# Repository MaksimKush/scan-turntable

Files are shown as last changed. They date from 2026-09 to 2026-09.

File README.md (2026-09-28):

# scan-turntable

Поворотный стол для фотограмметрии / 3D-сканирования. Без дисплея: управление по USB-Serial и через Wi‑Fi точку доступа.

## Оборудование

- Мотор: Minebea Mitsumi **PM42L-048-EPAO** ×**2** (маркировка **EM-182 TB9608E**; 48 шагов/об, 7.5°; Ø42×22.2 мм, вал Ø3 мм; bipolar) — азимут + наклон
- Шкив / шестерня на валу: **spur pinion m=2 z=12** (азимут → венец платформы); опционально GT2 12T для старых сборок
- Платформа сканирования: **Ø200 мм** с **зубчатым венцом** по ободу (печать на Ender 3 плашмя)
- Драйвер: **EasyDriver** (по умолчанию 1/8 шага → 384 микрошага/об; ток ~600 мА)
- Контроллер: **ESP32-C3**

## Прошивка

PlatformIO-проект (`platformio.ini`, `src/main.cpp`). Сборка и прошивка:

```bash
pio run -t upload
```

## Проводка ESP32-C3 → EasyDriver

Общая земля обязательна.

| ESP32-C3 | EasyDriver |
|---|---|
| GPIO4 | STEP |
| GPIO5 | DIR |
| GPIO6 | ENABLE (HIGH = катушки выкл.) |
| GPIO7 | кнопка на GND (старт съёмки, необязательно) |

MS1/MS2 не подключать — на плате уже 1/8. Питание мотора: 12 В на M+/GND EasyDriver (8–30 В). ESP32 питается от USB. Не подавать 5 V EasyDriver на пины 3.3 V ESP. Ток: потенциометр по TP1 ≈ 3.6 V (~600 мА).

## Управление

**Wi‑Fi AP:** `ScanTable` / `scan1234` → http://192.168.4.1 (веб-интерфейс).

**Serial (115200):**

- `SCAN <кадров> <пауза_мс>` — съёмка по кругу
- `JOG <градусы>` — поворот
- `SPEED <микрошагов/с>` — скорость
- `STOP` — стоп

## CAD

SolidWorks в `cad/` (контур мотора — `file_07_40.gif`; азимут — шестерня × венец, см. `GEAR_rim_pinion_notes.txt`).

### Мотор (user-owned) и привод
- `Motor_PM42L_048_EPAO.SLDPRT` — **перерисован пользователем**; скрипты **не** пересобирают этот файл
- `Pinion_Spur_Z12_M2.SLDPRT` — шестерня m=2, z=12, bore Ø3, L=8; торец вала +2 мм
- `Motor_PM42L_048_EPAO_Pinion.SLDASM` — мотор + шестерня
- `Pulley_GT2_12T.SLDPRT` / `Motor_PM42L_048_EPAO_Pulley.SLDASM` — прежний вариант с ремнём GT2 (архив)

### Двухосевой стол (как Revopoint A230), 2× PM42 — печать под Ender 3
Сборка: `Turntable_Revopoint2Motor.SLDASM`  
Motor1 = азимут (шестерня → зубчатый венец Ø200), Motor2 = наклон U-люльки.  
Корпус закрытый (Base_Housing + крышки). Заметки: `PRINT_Ender3_notes.txt`, `GEAR_rim_pinion_notes.txt`.

| Файл | Габарит | Стол 220×220 |
|---|---|---|
| **`Platform_RimGear_200.SLDPRT`** | **tip Ø200 × 14 мм, z=98, m=2** | OK |
| `Base_Housing.SLDPRT` | Ø200 × 36 | OK |
| `Cover_Base_Top.SLDPRT` | Ø200 × 4 | OK |
| `Yoke_Cradle_Base.SLDPRT` | ~192×55×8 | OK |
| `Yoke_Cradle_Arm_L/R.SLDPRT` | 28×48×12 | OK |
| `Cover_Arm_Motor.SLDPRT` | 55×58×22 | OK |
| `Pinion_Spur_Z12_M2.SLDPRT` | Ø28 × ~12 | OK |
| `Shaft_Tilt.SLDPRT` | Ø8 × 190 | лучше металлический пруток |

FDM: PLA/PETG. Цель по габариту как Revopoint: **Ø200 × ~H82**.

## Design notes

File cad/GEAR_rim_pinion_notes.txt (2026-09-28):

Azimuth drive — spur pinion x rim gear (шестерня + зубчатый венец / «рейка» по ободу)
==============================================================================
Module m = 2.0 mm
Pinion:  Pinion_Spur_Z12_M2.SLDPRT     z=12   d=24   da=28   df=19    face=8  bore=Ø3
Rim:     Platform_RimGear_200.SLDPRT   z=98   d=196  da=200  df=191   face=8 + deck 6
Center distance CD = (d_rim + d_pinion)/2 = 110 mm
Shaft tip past pinion = +2 mm
Ratio = 98/12 ≈ 8.17 : 1

Placement:
  Motor1 (user Motor_PM42L_048_EPAO) in Base_Housing at X=CD=110 mm, Z=floor
  Pinion on shaft: Z = tipZ - 2 - 8  (tip sticks +2 mm past pinion)
  Platform centered on Z axis; rim teeth mesh pinion at CD

USER MOTOR: Motor_PM42L_048_EPAO.SLDPRT is user-owned — do NOT auto-rebuild.
Assembly: Motor_PM42L_048_EPAO_Pinion.SLDASM
Turntable: Turntable_Revopoint2Motor.SLDASM

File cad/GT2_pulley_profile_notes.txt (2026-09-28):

GT2 belt → pulley profile notes
================================
Source belt drawing: cad/GT2-Belt_profile_1.jpg (+ user screenshot)
Motor outline: cad/file_07_40.gif (Minebea PM42 file_07_40)

Belt (drawing)
--------------
P            = 2.00 mm
Tooth height = 0.75 mm
Total height = 1.38 mm
PLD          = 0.254 mm
Tip radius   = R0.555  (center on tooth CL)
Flank radius = R1.00   (labeled center offset 0.40 from CL)
Root fillet  = R0.15

Pulley (12T, this rebuild)
-------------------------
z            = 12
PD           = z*P/π = 12*2/π = 7.6394 mm
OD           = PD − 2×PLD = 7.6394 − 0.508 = 7.1314 mm
Length L     = 6.00 mm (no flanges)
Bore         = Ø3.00 mm
Clearance    = 0.05 mm (groove larger than belt tooth; radial)

How belt → pulley was inverted
------------------------------
1. Belt land (valley between teeth) rides at pulley OD.
2. Belt tooth tip seats in the pulley groove → groove depth ≈ tooth height
   + clearance (0.75 + 0.05 = 0.80 mm from OD toward axis).
3. Groove outline = belt tooth outline with radii enlarged by clearance:
     tip  R = 0.555 + 0.05 = 0.605 mm, center on CL at y = H_clr − R_tip
     root R = 0.15  + 0.05 = 0.20  mm, centers at x = ±(0.75 + 0.02) mm
4. Tip and root circles (with clearance) intersect; join at the upper
   intersection → closed cut polygon, circular-patterned ×12.
5. Front Plane sketch; extrude/cut along +Z.

Why R1.00 @ 0.40 was not used as a separate flank arc
------------------------------------------------------
A G1 (tangent) blend of tip R0.555 and flank R1.00 requires center-distance
|Rf − Rt| = 0.445 mm. That forces 2×Rt = 1.11 > Rf = 1.00, so the near-side
tooth join is geometrically impossible (contact falls on the far side of the
tip circle). Empirically, published GT2 polygon profiles (and this drawing’s
tip/root) are well-fit by tip R0.555 + root R0.15 alone; the labeled R1@0.40
is retained as drawing intent but omitted from the CAD flank as a separate
arc. Lateral X-scale of a forced R1@0.40 construction was rejected as it
distorts the tip radius.

Groove radii centers (belt-local mm, y=0 at land, +y into groove)
-----------------------------------------------------------------
Tip center:   ( 0.000, 0.195)  R=0.605 (with clr; 0.195 = 0.80 − 0.605)
Root centers: (±0.770, 0.200)  R=0.200
Join (approx):(±0.596, 0.299)

Assembly
--------
Motor_PM42L_048_EPAO + Pulley_GT2_12T
Shaft tip (EPAO I1≈17 from boss) = 0.8 + 1.5 + 17 = 19.3 mm from Front
Pulley Z = 11.3 .. 17.3 mm  → tip past pulley end = +2.0 mm

Motor vs file_07_40.gif
-----------------------
GIF / catalog          Model (BuildPM42Epao)
Ø42                    Ø42
22.2 MAX               0.8 + 21.4 = 22.2
flange 0.8             0.8
boss Ø10 × 1.5         Ø10 × 1.5
P=49.5±0.1             49.5
2-Ø3.5                 Ø3.5
2-R3.75                R3.75
shaft Ø3               Ø3
I1 (EPAO ≈17)          17 mm from boss
rear 1 MAX             1.0
wire 12.7 / 5.5 MAX    12.7 / 5.5, θ=45°

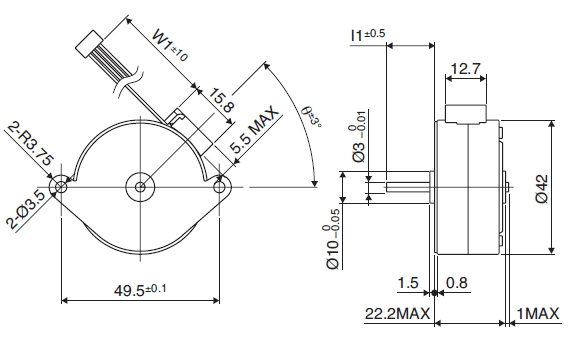
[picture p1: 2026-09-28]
cad/file_07_40.gif

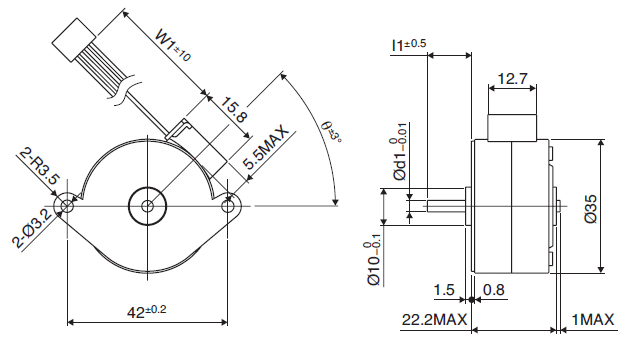
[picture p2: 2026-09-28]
cad/file_07_132.gif

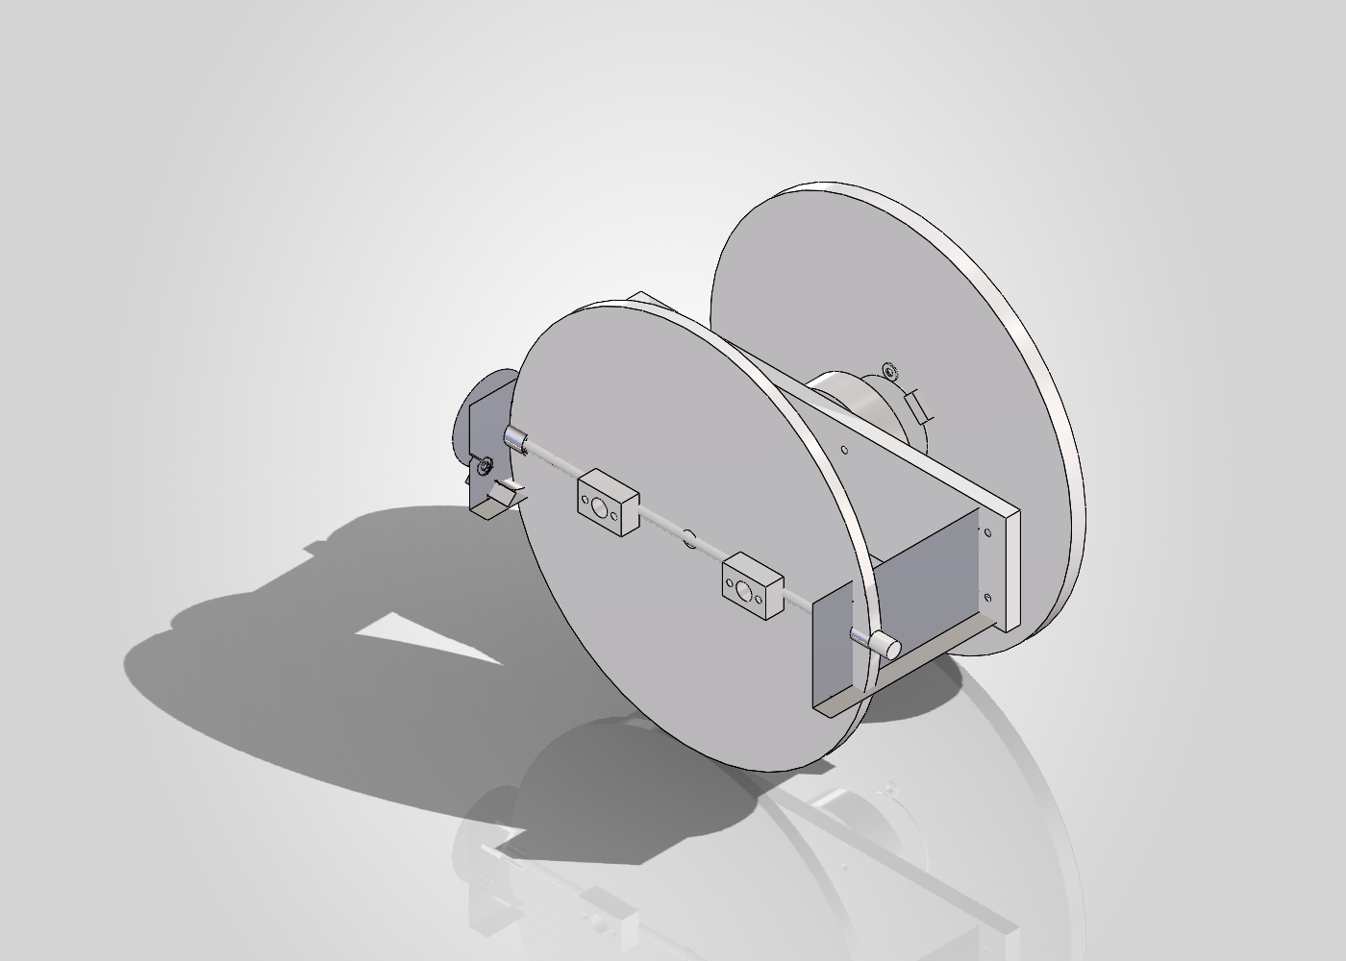
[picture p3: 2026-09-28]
cad/_preview_revopoint.png

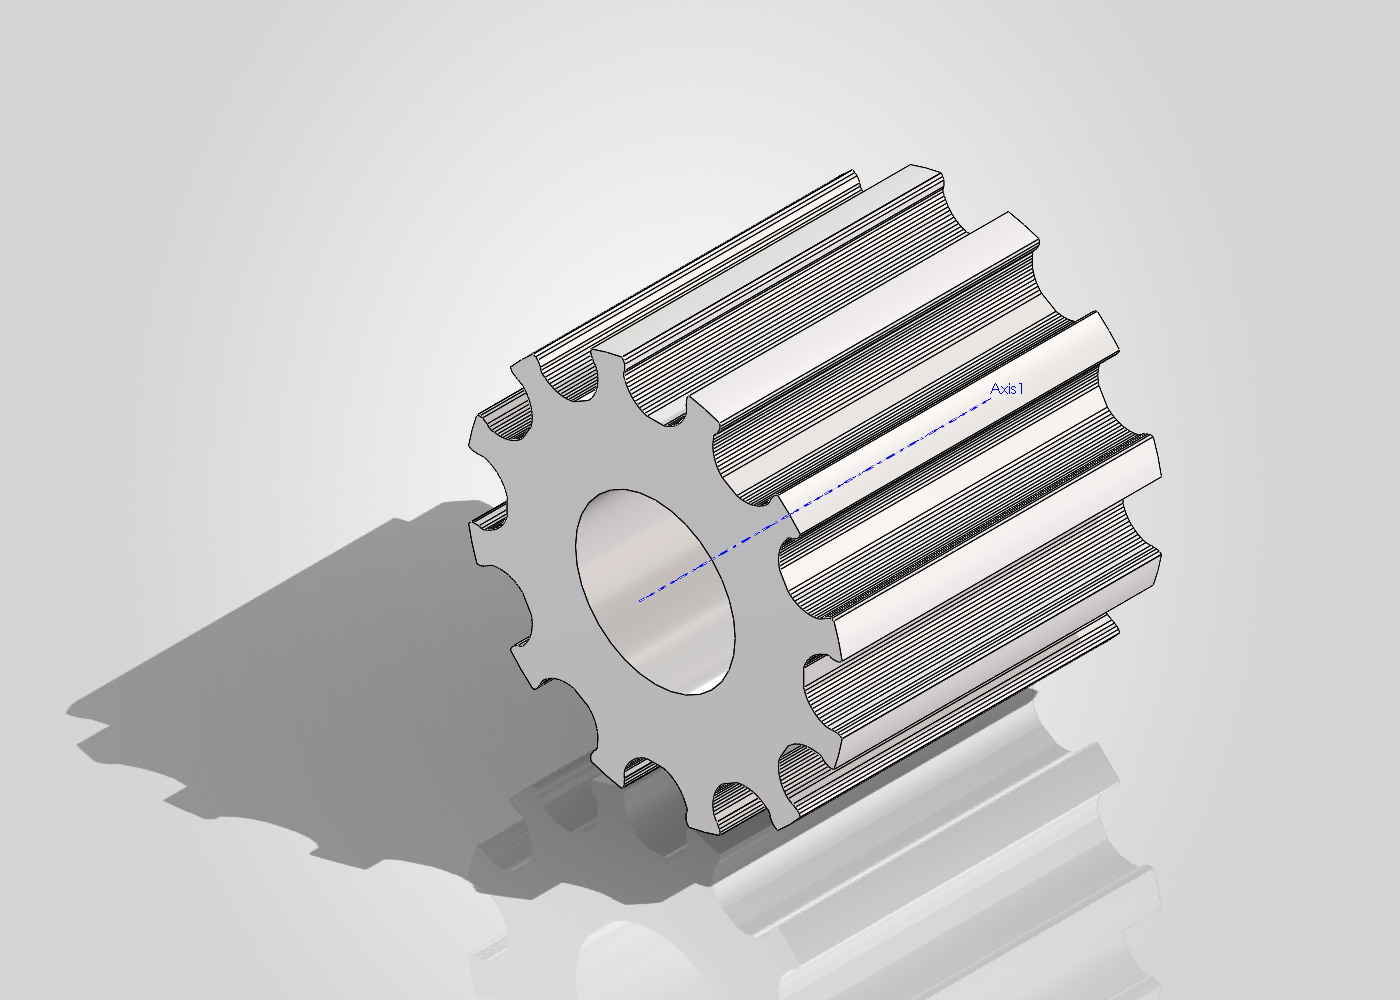
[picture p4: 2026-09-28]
cad/_preview_pulley.png

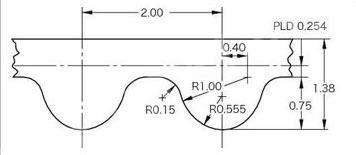
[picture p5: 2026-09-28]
cad/GT2-Belt_profile_1.jpg

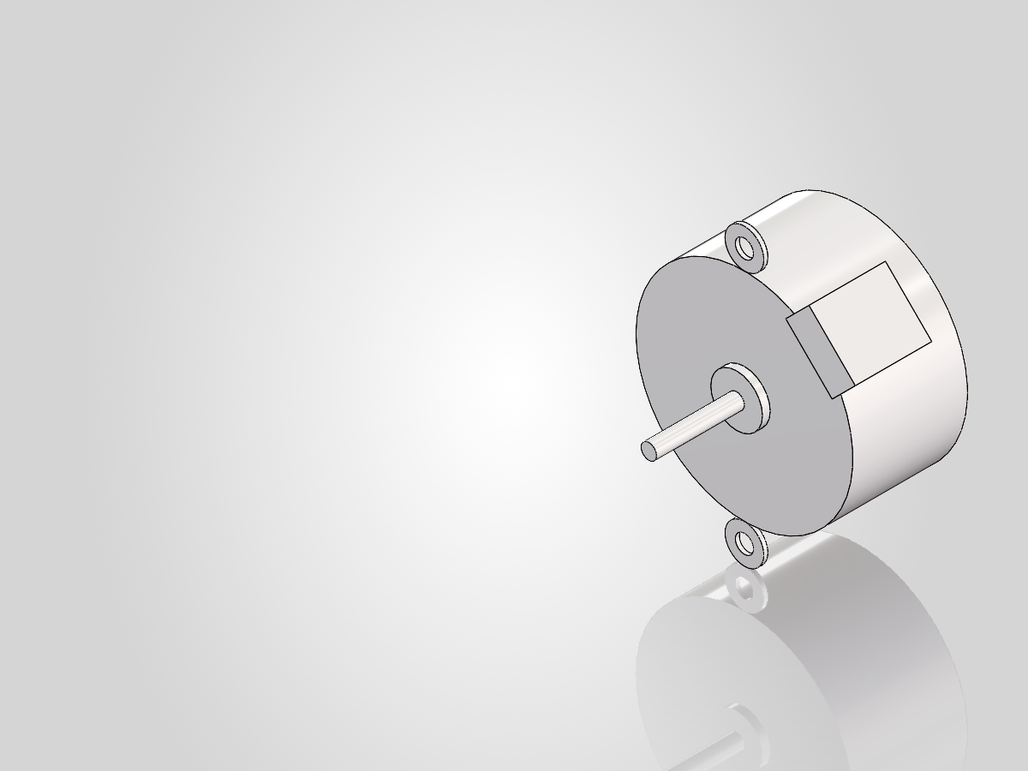
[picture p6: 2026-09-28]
cad/_preview_motor.png

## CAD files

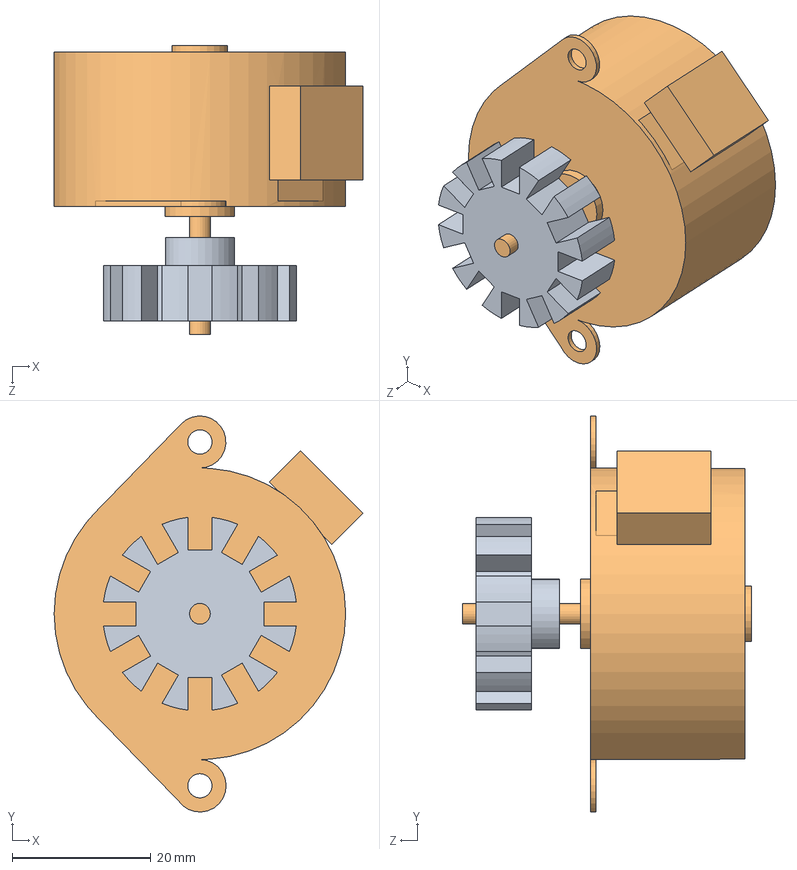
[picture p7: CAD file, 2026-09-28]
cad/Motor_PM42L_048_EPAO_Pinion.SLDASM
44.5 x 57.1 x 41.7 mm
Motor_PM42L_048_EPAO
Pinion_Spur_Z12_M2

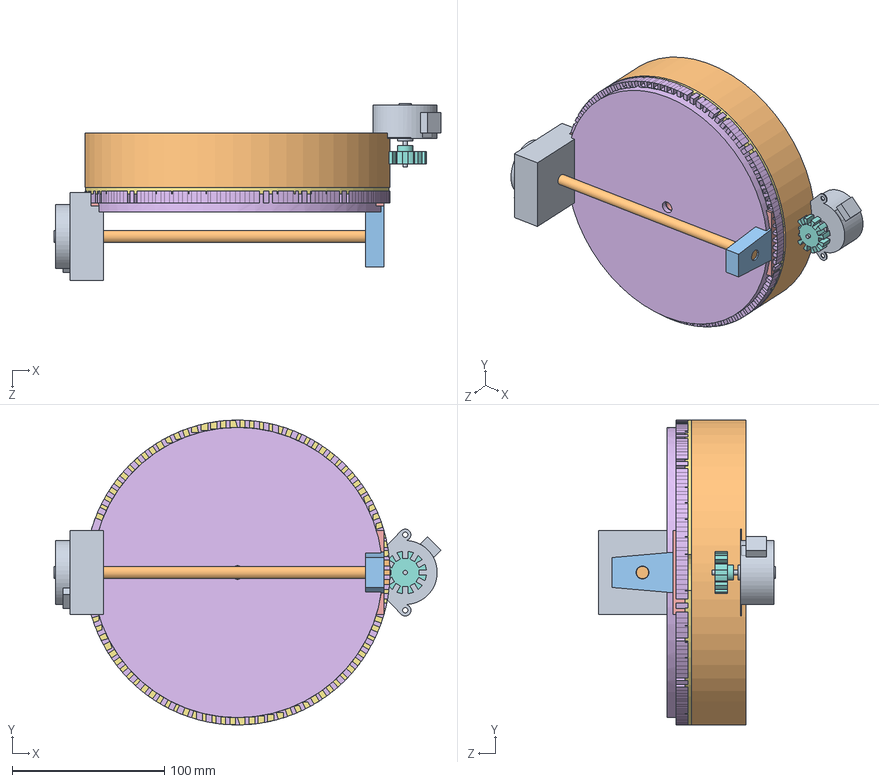
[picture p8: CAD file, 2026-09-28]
cad/Turntable_Revopoint2Motor.SLDASM
253.9 x 200.0 x 116.4 mm
Base_Housing
Motor_PM42L_048_EPAO x 2
Pinion_Spur_Z12_M2
Cover_Base_Top
Platform_RimGear_200
Yoke_Cradle_Base
Yoke_Cradle_Arm_L
Yoke_Cradle_Arm_R
Shaft_Tilt
Cover_Arm_Motor

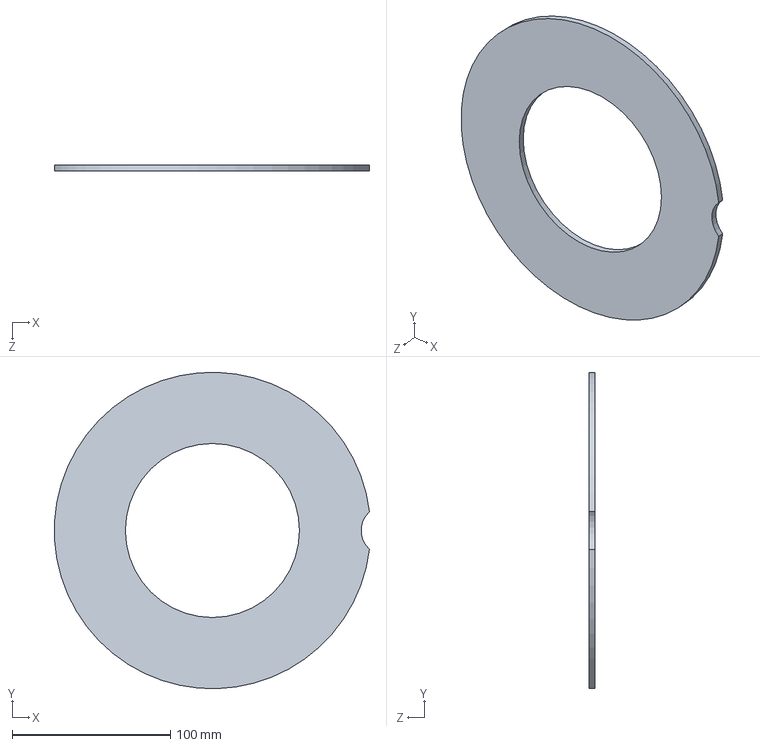
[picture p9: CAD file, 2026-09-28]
cad/Cover_Base_Top.SLDPRT
199.1 x 199.9 x 4.00 mm

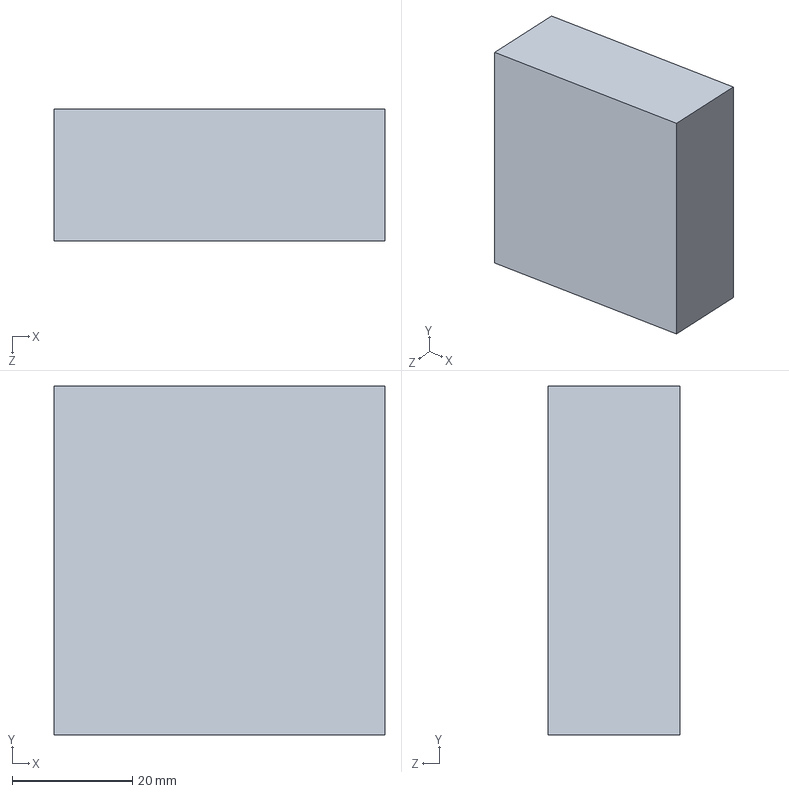
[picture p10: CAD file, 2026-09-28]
cad/Cover_Arm_Motor.SLDPRT
55.0 x 58.0 x 22.0 mm

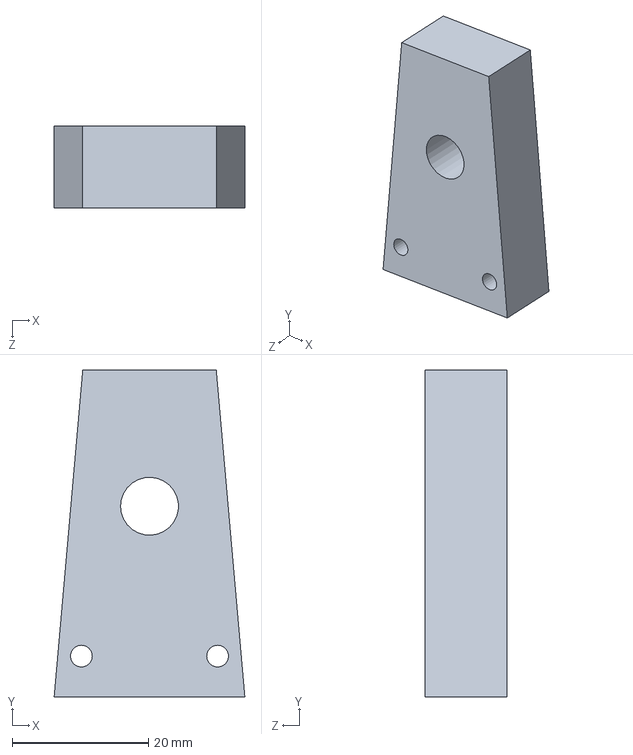
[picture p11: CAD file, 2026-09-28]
cad/Yoke_Cradle_Arm_R.SLDPRT
28.0 x 48.0 x 12.0 mm

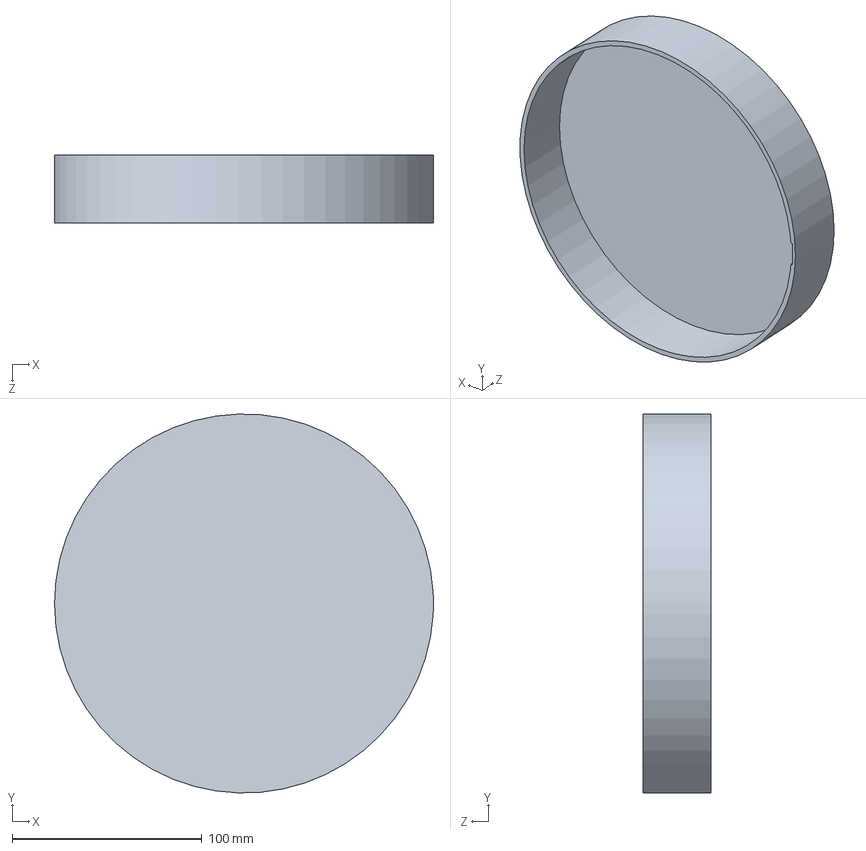
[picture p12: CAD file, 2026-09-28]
cad/Base_Housing.SLDPRT
200.0 x 199.9 x 36.0 mm

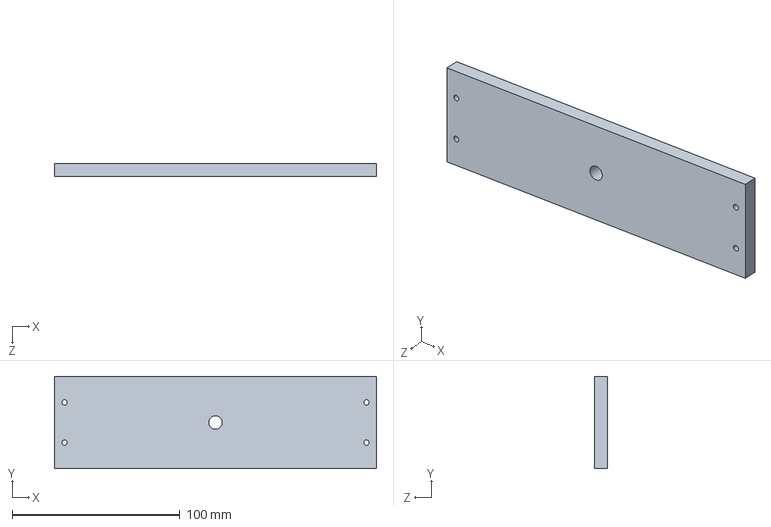
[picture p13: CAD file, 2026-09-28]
cad/Yoke_Cradle_Base.SLDPRT
192.0 x 55.0 x 8.00 mm

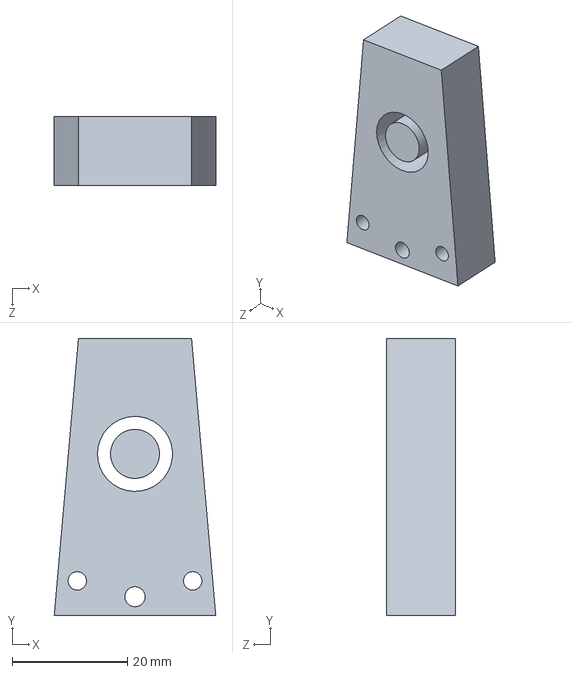
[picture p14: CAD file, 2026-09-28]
cad/Yoke_Cradle_Arm_L.SLDPRT
28.0 x 48.0 x 12.0 mm

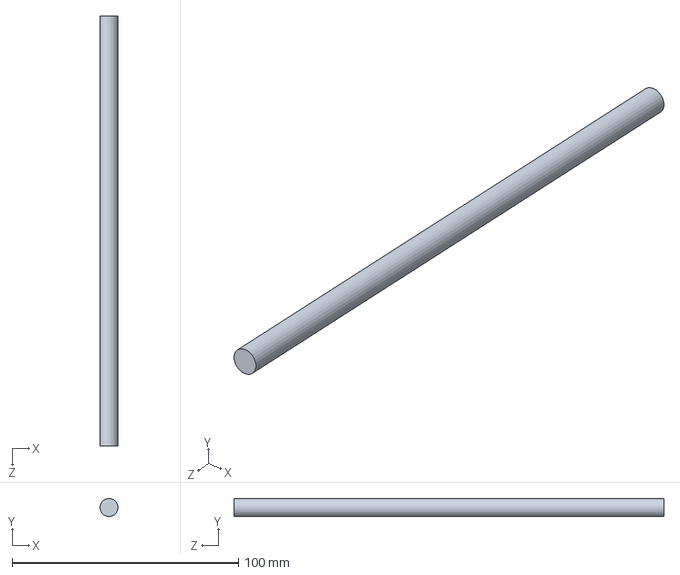
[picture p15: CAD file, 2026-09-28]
cad/Shaft_Tilt.SLDPRT
8.00 x 8.00 x 190.0 mm

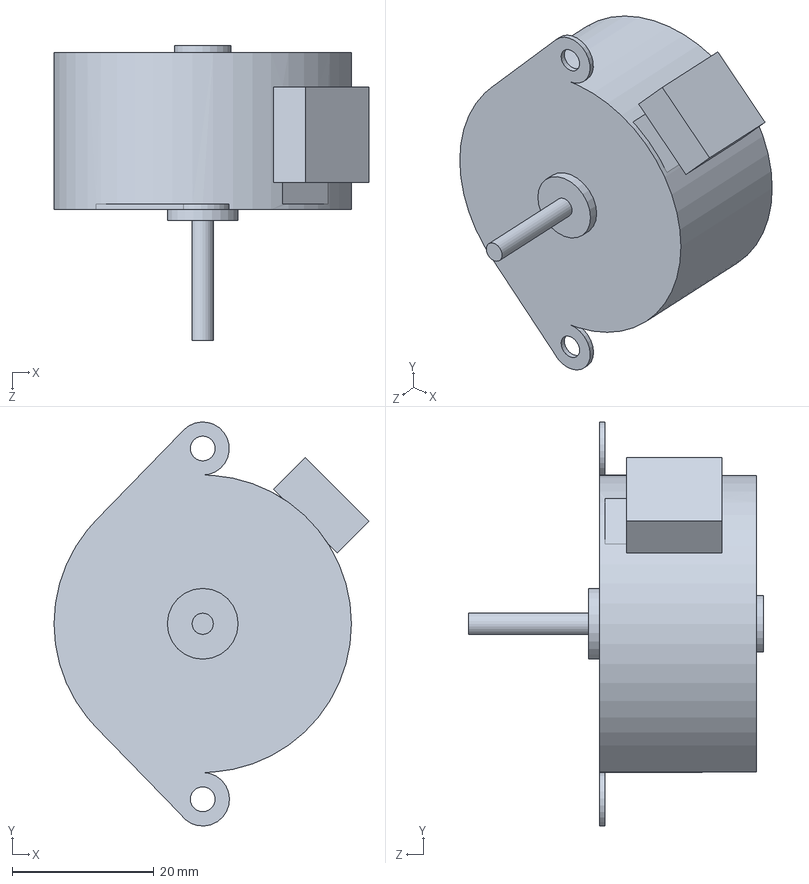
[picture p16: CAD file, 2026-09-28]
cad/Motor_PM42L_048_EPAO.SLDPRT
44.5 x 57.1 x 41.7 mm

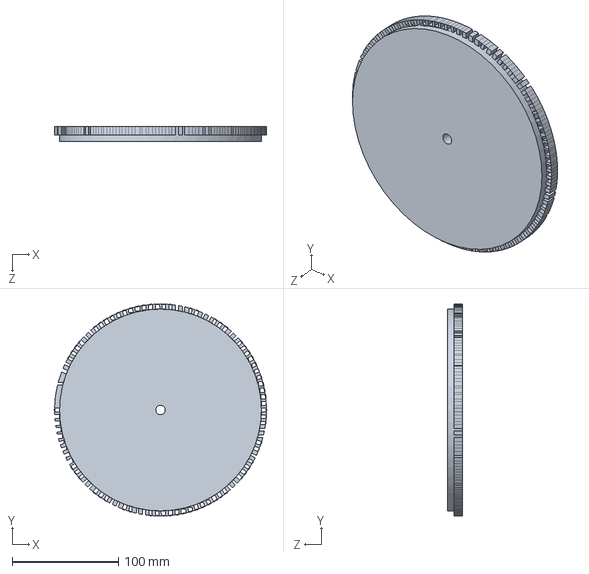
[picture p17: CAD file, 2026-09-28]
cad/Platform_RimGear_200.SLDPRT
200.0 x 200.0 x 14.0 mm

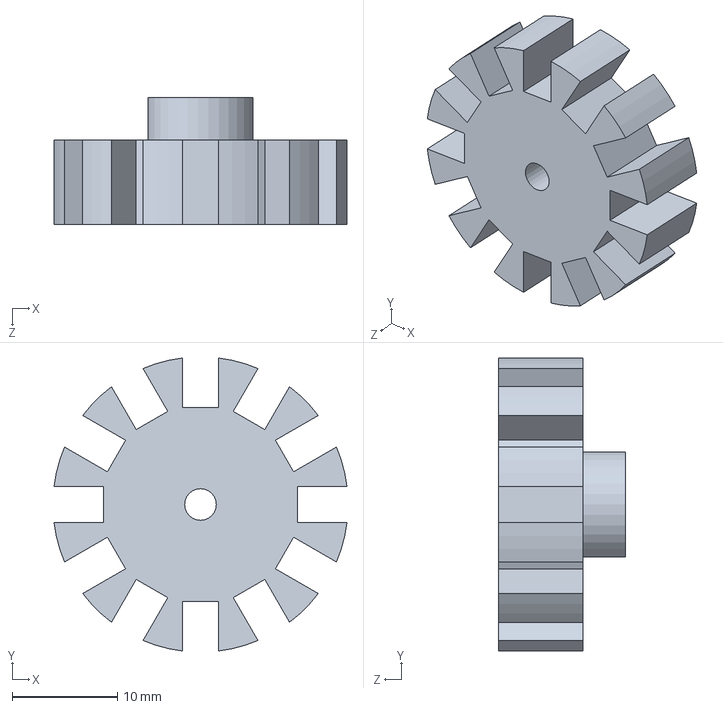
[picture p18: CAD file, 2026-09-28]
cad/Pinion_Spur_Z12_M2.SLDPRT
27.8 x 27.8 x 12.0 mm

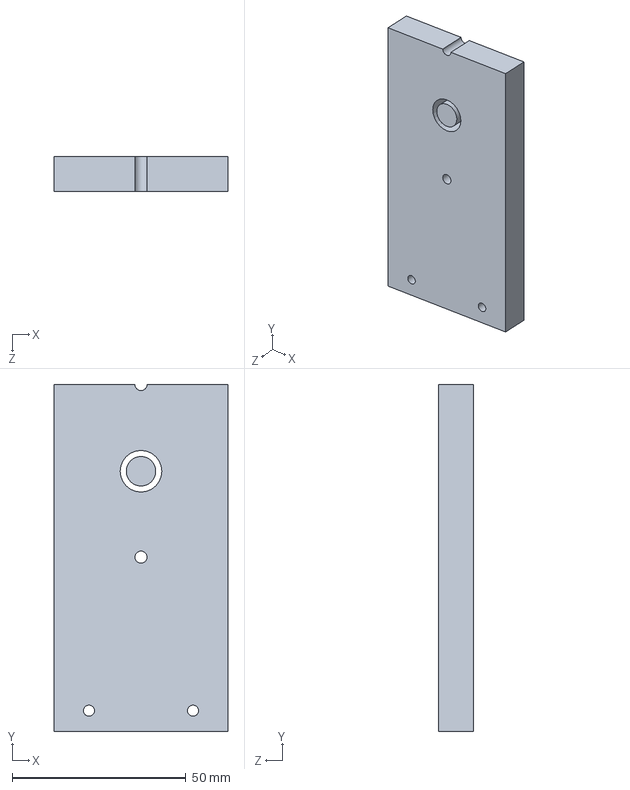
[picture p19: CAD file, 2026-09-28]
cad/Yoke_Arm_L.SLDPRT
50.0 x 100.0 x 10.0 mm

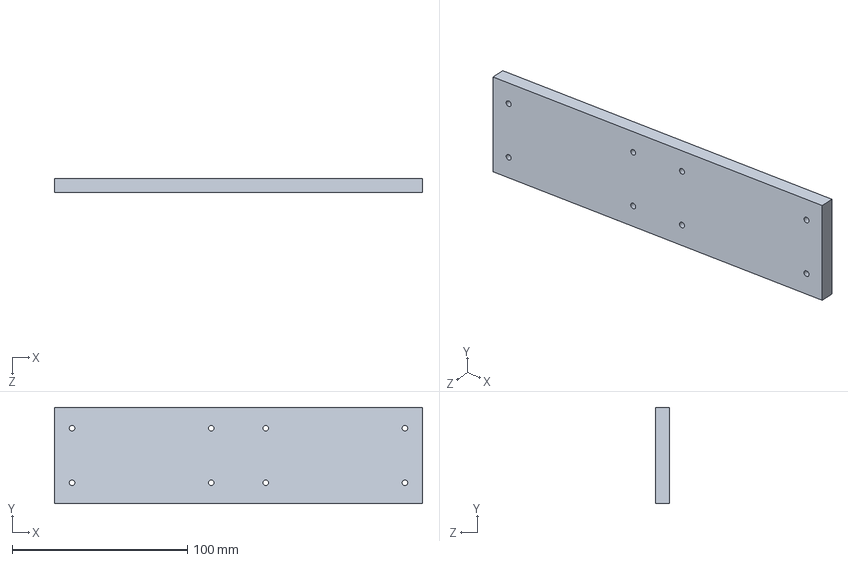
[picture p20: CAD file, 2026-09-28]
cad/Yoke_Base.SLDPRT
210.0 x 55.0 x 8.00 mm

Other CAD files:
cad/Motor_PM42L_048_EPAO_Pulley.SLDASM
cad/Motor_PM35L_N48_Pulley.SLDASM
cad/Turntable.SLDASM
cad/Motor_PM42L.SLDPRT
cad/Base.SLDPRT
cad/Base_Revopoint.SLDPRT
cad/Clamp_TiltShaft.SLDPRT
cad/Hub.SLDPRT
cad/Hub_Azimuth.SLDPRT
cad/Motor_PM35L_N48.SLDPRT
cad/Platform.SLDPRT
cad/Platform_Tilt.SLDPRT
cad/Pulley_GT2_12T.SLDPRT
cad/Yoke_Arm_R.SLDPRT

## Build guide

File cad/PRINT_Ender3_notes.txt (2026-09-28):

Печать под Ender 3 (стол 220×220 → макс ~210) — Revopoint-like Dual-axis (Ø200×~H82 target)
========================================================================================
Визуал (как Revopoint A230-II):
  — цилиндрический закрытый корпус базы Ø200
  — короткая U-люлька (cradle) со стойками
  — круглая платформа Ø200 с зубчатым венцом по ободу
  — крышки, прячущие моторы (Cover_Base_Top, Cover_Arm_Motor)

Печатные:
  Base_Housing.SLDPRT          Ø200 × 36
  Cover_Base_Top.SLDPRT        Ø200 × 4
  Platform_RimGear_200.SLDPRT  tipØ200 × 14 (зубья 8 + палуба 6) — ОДНА деталь
  Yoke_Cradle_Base.SLDPRT      ~192 × 55 × 8
  Yoke_Cradle_Arm_L/R.SLDPRT   28 × 48 × 12
  Cover_Arm_Motor.SLDPRT       55 × 58 × 22
  Pinion_Spur_Z12_M2.SLDPRT    Ø28 × ~12
  Shaft_Tilt.SLDPRT            Ø8 × 190 (лучше металлический прут)

Покупные / user (НЕ пересобирать скриптом):
  Motor_PM42L_048_EPAO ×2

Сборка / кинематика:
  Motor1 в базе → шестерня Pinion_Spur_Z12_M2 → венец Platform_RimGear (азимут 360°)
  Motor2 на левой стойке + крышка → наклон люльки (цель ±30° как Revopoint)

Скрипт: BuildRevopointLike.cs  (+ FixPlatformRim.cs если нужна пересборка венца)

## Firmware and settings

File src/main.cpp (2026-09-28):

// Поворотный стол для фотограмметрии.
// Мотор: Minebea Mitsumi PM42L-048-EPAO (маркировка EM-182 TB9608E) —
//   bipolar, 48 полных шагов/об (7.5°). Не путать с PM35.
// Драйвер: EasyDriver (schmalzhaus.com), по умолчанию 1/8 шага → 384 микрошага/об.
//   Ток ~600 мА (TP1 ≈ 3.6 В).
// Плата: ESP32-C3, дисплея нет. Управление: USB-Serial и Wi-Fi точка ScanTable.
//
// Провода ESP32-C3 → EasyDriver (общая земля обязательна):
//   GPIO4  STEP
//   GPIO5  DIR
//   GPIO6  ENABLE   (HIGH = катушки выключены)
//   GPIO7  кнопка на GND, старт съёмки (необязательно)
//   MS1 и MS2 не подключать — на плате уже 1/8
// Питание мотора: 12 В на M+ / GND EasyDriver (допустимо 8–30 В).
// ESP32 питается от USB. Не сажать 5V EasyDriver на пины 3.3 В ESP.
// Ток: крутить потенциометр, пока на TP1 не будет около 3.6 В (~600 мА).
// Шелкография MIN/MAX на EasyDriver часто перевёрнута — верить только вольтметру на TP1.

#include <Arduino.h>
#include <WiFi.h>
#include <WebServer.h>

static const int PIN_STEP = 4;
static const int PIN_DIR = 5;
static const int PIN_EN = 6;
static const int PIN_BTN = 7;

static const int FULL_STEPS = 48;
static const int MICRO = 8;
static const int STEPS_PER_REV = FULL_STEPS * MICRO;  // 384

static const char *AP_SSID = "ScanTable";
static const char *AP_PASS = "scan1234";

static WebServer server(80);

static bool dirPositive = true;
static int shots = 48;
static uint32_t dwellMs = 1500;
static uint32_t stepIntervalUs = 4000;  // 250 микрошагов/с

static long stepsLeft = 0;
static uint32_t lastStepUs = 0;
static bool pulseHigh = false;

enum RunMode { MODE_IDLE, MODE_JOG, MODE_DWELL, MODE_MOVE };
static RunMode mode = MODE_IDLE;
static int scanShot = 0;
static uint32_t dwellUntil = 0;

static String serialLine;

static void setEnabled(bool on) {
  digitalWrite(PIN_EN, on ? LOW : HIGH);
}

static void setDir(bool positive) {
  dirPositive = positive;
  digitalWrite(PIN_DIR, positive ? HIGH : LOW);
}

static long stepsForDegrees(float deg) {
  return lroundf(deg * STEPS_PER_REV / 360.0f);
}

static void startSteps(long n) {
  if (n < 0) {
    setDir(false);
    n = -n;
  } else if (n > 0) {
    setDir(true);
  }
  stepsLeft = n;
  if (n > 0) setEnabled(true);
}

static void stopAll() {
  stepsLeft = 0;
  pulseHigh = false;
  digitalWrite(PIN_STEP, LOW);
  mode = MODE_IDLE;
  scanShot = 0;
  setEnabled(false);
}

static void beginScan() {
  if (shots < 1) shots = 1;
  if (shots > STEPS_PER_REV) shots = STEPS_PER_REV;
  scanShot = 0;
  mode = MODE_DWELL;
  dwellUntil = millis() + dwellMs;
  setEnabled(true);
  Serial.printf("scan start shots=%d dwell=%lu ms\n", shots, (unsigned long)dwellMs);
  Serial.println("shot 1");
}

static void beginJogDeg(float deg) {
  mode = MODE_JOG;
  startSteps(stepsForDegrees(deg));
  Serial.printf("jog %.2f deg (%ld steps)\n", deg, stepsForDegrees(deg));
}

static void serviceStepper() {
  if (stepsLeft <= 0) {
    if (pulseHigh) {
      digitalWrite(PIN_STEP, LOW);
      pulseHigh = false;
    }
    return;
  }

  uint32_t now = micros();
  if (pulseHigh) {
    if (now - lastStepUs >= 20) {
      digitalWrite(PIN_STEP, LOW);
      pulseHigh = false;
      lastStepUs = now;
      stepsLeft--;
    }
    return;
  }

  if (now - lastStepUs < stepIntervalUs) return;
  digitalWrite(PIN_STEP, HIGH);
  pulseHigh = true;
  lastStepUs = now;
}

static void serviceMotion() {
  if (mode == MODE_JOG && stepsLeft <= 0 && !pulseHigh) {
    mode = MODE_IDLE;
    setEnabled(false);
    Serial.println("jog done");
    return;
  }

  if (mode == MODE_MOVE && stepsLeft <= 0 && !pulseHigh) {
    mode = MODE_DWELL;
    dwellUntil = millis() + dwellMs;
    Serial.printf("shot %d\n", scanShot + 1);
    return;
  }

  if (mode != MODE_DWELL || millis() < dwellUntil) return;

  scanShot++;
  if (scanShot >= shots) {
    Serial.println("scan done");
    stopAll();
    return;
  }

  long prev = (long)(scanShot - 1) * STEPS_PER_REV / shots;
  long next = (long)scanShot * STEPS_PER_REV / shots;
  mode = MODE_MOVE;
  startSteps(next - prev);
}

static const char PAGE[] PROGMEM = R"HTML(
<!DOCTYPE html>
<html lang="ru">
<head>
<meta charset="utf-8">
<meta name="viewport" content="width=device-width,initial-scale=1">
<title>Стол 3D-скана</title>
<style>
  body{font-family:sans-serif;background:#111;color:#eee;margin:0;padding:16px}
  h1{font-size:1.2rem}
  label{display:block;margin:10px 0 4px;color:#aaa}
  input{width:100%;box-sizing:border-box;padding:10px;font-size:1rem;background:#222;color:#fff;border:1px solid #444}
  button{width:100%;margin-top:10px;padding:12px;font-size:1rem;border:0;border-radius:8px}
  .go{background:#2a7;color:#fff}.stop{background:#a33;color:#fff}.jog{background:#246;color:#fff}
  #st{margin-top:14px;color:#9cf}
</style>
</head>
<body>
<h1>Поворотный стол</h1>
<label>Кадров на оборот</label>
<input id="shots" type="number" min="1" max="384" value="48">
<label>Пауза на кадр, мс</label>
<input id="dwell" type="number" min="100" max="20000" value="1500">
<button class="go" onclick="go()">Старт съёмки</button>
<button class="stop" onclick="cmd('/stop')">Стоп</button>
<button class="jog" onclick="cmd('/jog?deg=15')">+15°</button>
<button class="jog" onclick="cmd('/jog?deg=-15')">−15°</button>
<button class="jog" onclick="cmd('/jog?deg=360')">Полный оборот</button>
<p id="st"></p>
<script>
function cmd(u){fetch(u).then(r=>r.text()).then(t=>{document.getElementById('st').textContent=t})}
function go(){
  const s=document.getElementById('shots').value;
  const d=document.getElementById('dwell').value;
  cmd('/scan?shots='+s+'&dwell='+d);
}
setInterval(()=>fetch('/status').then(r=>r.text()).then(t=>{document.getElementById('st').textContent=t}),1000);
</script>
</body>
</html>
)HTML";

static String statusText() {
  const char *m = "idle";
  if (mode == MODE_DWELL) m = "dwell";
  if (mode == MODE_MOVE) m = "scan";
  if (mode == MODE_JOG) m = "jog";
  int shown = (mode == MODE_IDLE) ? 0 : scanShot + 1;
  char buf[160];
  snprintf(buf, sizeof(buf), "mode=%s shot=%d/%d steps_left=%ld",
           m, shown, shots, stepsLeft);
  return String(buf);
}

static void handleRoot() { server.send_P(200, "text/html", PAGE); }

static void handleStatus() { server.send(200, "text/plain", statusText()); }

static void handleStop() {
  stopAll();
  server.send(200, "text/plain", "stopped");
}

static void handleScan() {
  if (server.hasArg("shots")) shots = server.arg("shots").toInt();
  if (server.hasArg("dwell")) dwellMs = (uint32_t)server.arg("dwell").toInt();
  if (shots < 1) shots = 1;
  if (shots > STEPS_PER_REV) shots = STEPS_PER_REV;
  if (dwellMs < 50) dwellMs = 50;
  stopAll();
  beginScan();
  server.send(200, "text/plain", statusText());
}

static void handleJog() {
  float deg = server.hasArg("deg") ? server.arg("deg").toFloat() : 15.0f;
  stopAll();
  beginJogDeg(deg);
  server.send(200, "text/plain", statusText());
}

static void handleSerial() {
  while (Serial.available()) {
    char c = (char)Serial.read();
    if (c == '\r') continue;
    if (c != '\n') {
      if (serialLine.length() < 80) serialLine += c;
      continue;
    }
    serialLine.trim();
    String u = serialLine;
    u.toUpperCase();
    if (u.startsWith("SCAN")) {
      int s = shots;
      int d = (int)dwellMs;
      sscanf(serialLine.c_str(), "%*s %d %d", &s, &d);
      shots = s;
      dwellMs = (uint32_t)d;
      stopAll();
      beginScan();
    } else if (u.startsWith("JOG")) {
      float deg = 15;
      sscanf(serialLine.c_str(), "%*s %f", &deg);
      stopAll();
      beginJogDeg(deg);
    } else if (u == "STOP") {
      stopAll();
      Serial.println("stopped");
    } else if (u.startsWith("SPEED")) {
      int sps = 250;
      sscanf(serialLine.c_str(), "%*s %d", &sps);
      if (sps < 20) sps = 20;
      if (sps > 2000) sps = 2000;
      stepIntervalUs = 1000000UL / (uint32_t)sps;
      Serial.printf("speed %d ustep/s\n", sps);
    } else {
      Serial.println("SCAN <кадров> <пауза_мс>");
      Serial.println("JOG <градусы>");
      Serial.println("SPEED <микрошагов/с>");
      Serial.println("STOP");
    }
    serialLine = "";
  }
}

static bool btnWasDown = false;
static uint32_t btnLockUntil = 0;

static void serviceButton() {
  if (millis() < btnLockUntil) return;
  bool down = digitalRead(PIN_BTN) == LOW;
  if (down && !btnWasDown) {
    btnLockUntil = millis() + 250;
    if (mode == MODE_IDLE) beginScan();
    else stopAll();
  }
  btnWasDown = down;
}

void setup() {
  pinMode(PIN_STEP, OUTPUT);
  pinMode(PIN_DIR, OUTPUT);
  pinMode(PIN_EN, OUTPUT);
  pinMode(PIN_BTN, INPUT_PULLUP);
  digitalWrite(PIN_STEP, LOW);
  setDir(true);
  setEnabled(false);

  Serial.begin(115200);
  delay(300);
  Serial.println("scan-turntable ESP32-C3");
  Serial.println("PM42L-048-EPAO 48 step, EasyDriver 1/8 -> 384 ustep/rev");
  Serial.println("SCAN 48 1500 | JOG 15 | SPEED 250 | STOP");

  WiFi.mode(WIFI_AP);
  WiFi.softAP(AP_SSID, AP_PASS);
  Serial.print("AP ");
  Serial.print(AP_SSID);
  Serial.print("  http://");
  Serial.println(WiFi.softAPIP());

  server.on("/", handleRoot);
  server.on("/status", handleStatus);
  server.on("/scan", handleScan);
  server.on("/jog", handleJog);
  server.on("/stop", handleStop);
  server.begin();
}

void loop() {
  server.handleClient();
  handleSerial();
  serviceButton();
  serviceStepper();
  serviceMotion();
}

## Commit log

2026-09-24 Initial commit: ESP32-C3 photogrammetry turntable firmware and SolidWorks CAD.
    [Base.SLDPRT, Hub.SLDPRT, Motor_PM42L.SLDPRT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]
2026-09-28 Switch CAD to PM35L-N48 with GT2 12T pulley (O8x6, tip +2 mm).
    [Base.SLDPRT, Hub.SLDPRT, Motor_PM35L_N48.SLDPRT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]
2026-09-28 Rebuild PM35L-N48 and GT2 pulley on Front plane with circular teeth
    [Motor_PM35L_N48.SLDPRT, Motor_PM35L_N48_Pulley.SLDASM, Pulley_GT2_12T.SLDPRT]
2026-09-28 GT2 real tooth profile (no flange); motor PM42L-048-EPAO
    [Motor_PM42L_048_EPAO.SLDPRT, Motor_PM42L_048_EPAO_Pulley.SLDASM, Pulley_GT2_12T.SLDPRT]
2026-09-28 Fix PM42 assembly Z placement; document EM-182 TB9608E
    [Motor_PM42L_048_EPAO_Pulley.SLDASM]
2026-09-28 Add Ender3-ready 2-motor Revopoint turntable with 200mm platform.
    GT2 pulley grooves from belt tip/root radii; PM42 matches file_07_40; yoke split for 220x220 bed.
    [Base_Revopoint.SLDPRT, Clamp_TiltShaft.SLDPRT, Hub_Azimuth.SLDPRT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]
2026-09-28 Revopoint-like dual-axis: user motor + pinion/rim azimuth drive.
    Preserve user-redrawn Motor_PM42L_048_EPAO; enclosed Ø200 housing and U-cradle; spur m=2 z12/z98 mesh.
    [Base_Housing.SLDPRT, Cover_Arm_Motor.SLDPRT, Cover_Base_Top.SLDPRT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]
